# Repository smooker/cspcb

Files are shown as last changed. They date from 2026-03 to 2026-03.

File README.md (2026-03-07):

# stepper_sc — STM32F411 Stepper Controller PCB

Single-axis stepper motor controller board built around the **WeAct STM32F411CEU6 Black Pill v3.1**.

Drives a **CWD556** opto-isolated stepper driver (PUL/DIR interface) from MCU outputs via NPN buffer stage.

## Block Diagram

```
24V ──── 78M05 ──── +5V ──── Black Pill (3.3V regulator on-board)
                              │
                    PB10 ─── R1/R2/Q1 ─── J2 (PUL → CWD556)
                    PB14 ─── R3/R4/Q2 ─── J3 (DIR → CWD556)
                    PA3  ─── J4 (Endstop L)
                    PA4  ─── J5 (Endstop R)
                    PA6  ─── J6 (Jog L)
                    PA7  ─── J7 (Jog R)
                    PB0  ─── J8 (Step L)
                    PB1  ─── J9 (Step R)
                    PB15 ─── J10 (Buzzer)
```

## Hardware

| Ref | Value | Function |
|-----|---|---|
| U1 | 78M05 | 24V → 5V regulator |
| Q1, Q2 | BC547 | NPN buffer (PUL, DIR) |
| R1, R3 | 1kΩ | Base resistor |
| R2, R4 | 10kΩ | Base pull-down |
| C1 | 47µF | Regulator input bulk |
| C2, C4 | 100nF | Regulator decoupling |
| C3 | 100µF | Regulator output bulk |
| C5 | 100nF | Black Pill VIN decoupling |
| J1 | 2-pin screw | 24V power input |
| J2 | 2-pin screw | PUL output to CWD556 |
| J3 | 2-pin screw | DIR output to CWD556 |
| J4–J10 | 2-pin screw | Signal terminals |
| J11A, J11B | 1×20 header | Black Pill socket |

## Pipeline

Schematic and netlist are **generated from firmware source** — `main.h` is the single source of truth for MCU pin assignments.

```
firmware/Core/Inc/main.h
        │
        ▼ fw_to_net.py
howto_sch_and_then_api/stepper_sc.net
        │
        ▼ howto_sch_and_then_api/stepper_sc_gen.py
stepper_sc/stepper_sc.kicad_sch
```

### Re-generating after pin changes

```bash
# Activate venv (needs kicad-sch-api)
source venv/bin/activate

# Step 1: netlist from firmware
python3 fw_to_net.py

# Step 2: schematic from netlist
python3 howto_sch_and_then_api/stepper_sc_gen.py
```

### Setup

```bash
python3 -m venv venv
venv/bin/pip install kicad-sch-api

# KiCad symbol libraries — set path to your KiCad install
# e.g. /usr/share/kicad/symbols
ln -s /path/to/kicad/symbols kicad_sym
```

## Firmware

See `firmware/` for STM32 application source (`Core/`).

Requires ST HAL (`Drivers/`) — generate via STM32CubeMX or download from [st.com](https://www.st.com).

Build:
```bash
cd firmware && make
```

Flash via Black Magic Probe:
```bash
arm-none-eabi-gdb -x script2.gdb build/stepper.elf
```

See `doc/build-and-debug.md` for full build, flash and debug instructions.

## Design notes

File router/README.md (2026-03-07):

# smooker-router

A homegrown PCB autorouter for KiCad 9 via IPC (kipy).

## Architecture

```
grid.py        — Board grid, obstacle map (tracks, pads, courtyards)
astar.py       — A* pathfinder on the grid (supports F.Cu + B.Cu + vias)
segments.py    — Convert A* path → 45° track segments
router.py      — Main: query board, build ratsnest, route net by net, push to KiCad
```

## Grid
- Resolution: 0.1mm per cell (configurable)
- Layers: F.Cu, B.Cu (two-layer board)
- Obstacles: existing tracks (inflated by clearance), pad copper, courtyard edges
- Vias: allowed anywhere not blocked, cost penalty applied

## Pathfinder (A*)
- 8-directional moves (N, NE, E, SE, S, SW, W, NW) on each layer
- Via transition: move between layers at same cell (cost = via penalty)
- Heuristic: Chebyshev distance (optimal for 45° routing)
- Cost: straight=1.0, diagonal=1.0 (equal on grid), via=10.0

## Segment generation
- Collapse collinear A* cells into minimal segments
- Output: list of (x0,y0,x1,y1,layer) tuples → Track objects

## Routing order
- Nets sorted by: shortest Manhattan distance first (easiest first)
- After each net: update obstacle map with new tracks

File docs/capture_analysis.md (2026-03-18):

# Анализ на захванатите сигнали vs. изчисления на фърмуера

Дата: 2026-03-13, обновен: 2026-03-18

Инструментариум: FX2 Saleae Logic (sigrok/fx2lafw), канали D7=PULSE (PB10), D6=DIR (PB14).

## 1. Симетрични рампи (dvdtacc = dvdtdecc = 50 mm/s²)

### Параметри

| Параметър | Стойност | Описание |
|---|---|---|
| spmm | 400 стъпки/mm | 1600 стъпки/оборот ÷ 4 mm/оборот |
| mmpsmax | 10.0 mm/s | Максимална скорост |
| mmpsmin | 1.0 mm/s | Минимална скорост |
| dvdtacc | 50.0 mm/s² | Ускорение |
| dvdtdecc | 50.0 mm/s² | Забавяне |

Файл: `capture_combo.sr` (100 kHz)

### Брой импулси

| Движение | Очаквано | Измерено | Резултат |
|---|---|---|---|
| mover 1 (1 mm) | 400 | 400 | точно |
| movel 1 (1 mm) | 400 | 400 | точно |
| mover 5 (5 mm) | 2000 | 2000 | точно |
| movel 5 (5 mm) | 2000 | 2000 | точно |

### Максимална скорост

| Движение | Профил | Очаквано | Измерено | Разлика |
|---|---|---|---|---|
| move 1 | триъгълен | 7.07 mm/s (354 µs) | 7.58 mm/s (330 µs) | 7.1% |
| move 5 | трапецовиден | 10.00 mm/s (250 µs) | 10.42 mm/s (240 µs) | 4.2% |

Разликите идват от квантоването при 100 kHz (±10 µs = ±4% при 250 µs период).

## 2. Асиметрични рампи (dvdtacc=50, dvdtdecc=100 mm/s²)

### Параметри

| Параметър | Стойност |
|---|---|
| dvdtacc | 50.0 mm/s² |
| dvdtdecc | 100.0 mm/s² |
| accelSize | ~325 стъпки |
| decelSize | ~162 стъпки |

Файл: `capture_combo_final_speed.sr` (1 MHz)

### Измерени профили

| # | Движение | Импулси | Продължителност | Профил | Посока |
|---|---|---|---|---|---|
| 1 | movel 1 | 400 | 199 ms | асим. трапец | CCW (L) |
| 2 | mover 1 | 400 | 199 ms | асим. трапец | CW (R) |
| 3 | movel 5 | 2000 | 594 ms | асим. трапец | CCW (L) |
| 4 | mover 5 | 2000 | 594 ms | асим. трапец | CW (R) |

### Детайли на рамп фазите

#### Къси движения (1 mm = 400 стъпки)

| Фаза | Стъпки | Продължителност | Период |
|---|---|---|---|
| Ускорение | 221 | 123.8 ms | 2148→290 µs |
| Плато | 72 | 21.9 ms | ~290 µs |
| Забавяне | 106 | 53.7 ms | 290→2148 µs |

Пикова скорост: **8.62 mm/s** (не достига mmpsmax=10 — почти триъгълен профил)
Accel/Decel време: **2.30x** (очаквано ~2.0x)

#### Дълги движения (5 mm = 2000 стъпки)

| Фаза | Стъпки | Продължителност | Период |
|---|---|---|---|
| Ускорение | 325 | 153.9 ms | 2148→240 µs |
| Плато | 1512 | 364.2 ms | 240 µs |
| Забавяне | 162 | 76.3 ms | 240→2148 µs |

Пикова скорост: **10.42 mm/s** (mmpsmax, +4.2% от квантоване)
Accel/Decel време: **2.02x** (очаквано 2.0x — перфектно!)

### Асиметрия — анализ

Забавянето е 2× по-стръмно от ускорението (dvdtdecc/dvdtacc = 100/50 = 2).
Измерено:

```
Трапец (5 mm):  accel = 153.9 ms, decel = 76.3 ms → ratio = 2.02x  ✓
Триъгълен (1 mm): accel = 123.8 ms, decel = 53.7 ms → ratio = 2.30x  (~2x + edge effects)
```

При кратките движения ratio-то е малко по-високо (2.3x вместо 2.0x) заради
ефектите от дискретизацията на рамп таблицата при ниските скорости.

### Визуален профил (ASCII)

```
Скорост (mm/s)
  10 |         ___________________________
     |        /                           \
   8 |       / accel=50 mm/s²    decel=100 \  mm/s²
     |      /                               \
   4 |     /                                 \
     |    /                                   \
   1 |___/                                     \___
     |
     └──────────────────────────────────────────── Време
      0    154 ms        518 ms         594 ms
           ←accel→       ←const→       ←decel→
           325 st.       1512 st.       162 st.
```

Забавянето заема **половината** от времето на ускорението, но използва
**половината** от стъпките — двойно по-стръмен наклон на скоростната крива.

## 3. Квантоване и грешки

### Честота на дискретизация

| Честота | Резолюция | Грешка при 250 µs | Грешка при 2500 µs |
|---|---|---|---|
| 100 kHz | 10 µs | ±4.0% | ±0.4% |
| 1 MHz | 1 µs | ±0.4% | ±0.04% |

Захващанията при 1 MHz (capture_combo_final_speed.sr) дават значително
по-точни резултати.

### Систематични грешки

1. **Измереният min период е 240 µs вместо 250 µs** — фазово подравняване
   между TIM2 (96 MHz) и FX2 (48 MHz, от USB SOF). Разлика = 1 семпъл при
   100 kHz, 10 семпла при 1 MHz → вътрешна закръгляне на TIM2 ARR.

2. **Максимален период 2148 µs вместо 2500 µs** — първият и последният
   импулс от рампата може да не попаднат в захващането (setup delay).

## 4. Заключения

1. **Броят импулси е точен** — spmm=400, всяко движение дава точния брой стъпки
2. **Асиметричните рампи работят коректно** — dvdtdecc=2×dvdtacc дава 2× по-стръмно забавяне
3. **Accel/Decel ratio = 2.02x** за трапецовиден профил (перфектно съвпадение с теорията)
4. **Триъгълният профил** коректно не достига mmpsmax при къси движения
5. **Двете посоки са идентични** — DIR инверсия не влияе на timing-а

## Захванати файлове

| Файл | Честота | Съдържание | Параметри |
|---|---|---|---|
| `capture_all.sr` | 1 MHz | Pre-fix, `move 10`, decel bug | dvdtacc=dvdtdecc=50 |
| `capture_both.sr` | 100 kHz | Post-fix, `mover 5` + `movel 5` | dvdtacc=dvdtdecc=50 |
| `capture_both_speed.sr` | 100 kHz | Same + speed analog | dvdtacc=dvdtdecc=50 |
| `capture_combo.sr` | 100 kHz | 2 tri + 2 trap, symmetric | dvdtacc=dvdtdecc=50 |
| `capture_combo_final_speed.sr` | 1 MHz | 2 tri + 2 trap, asymmetric + speed | dvdtacc=50, dvdtdecc=100 |
| `capture_combo4_speed.sr` | 1 MHz | Same, longer capture window | dvdtacc=50, dvdtdecc=100 |
| `capture_jog_speed.sr` | 1 MHz | Jog button press/release | — |
| `capture_triangle_speed.sr` | 100 kHz | Triangle profile only + speed | dvdtacc=dvdtdecc=50 |

### Viewing

```bash
cd firmware
./go.sh view ../capture_combo_final_speed.sr   # asymmetric combo
./go.sh speed ../capture_both.sr               # symmetric + speed channel
```

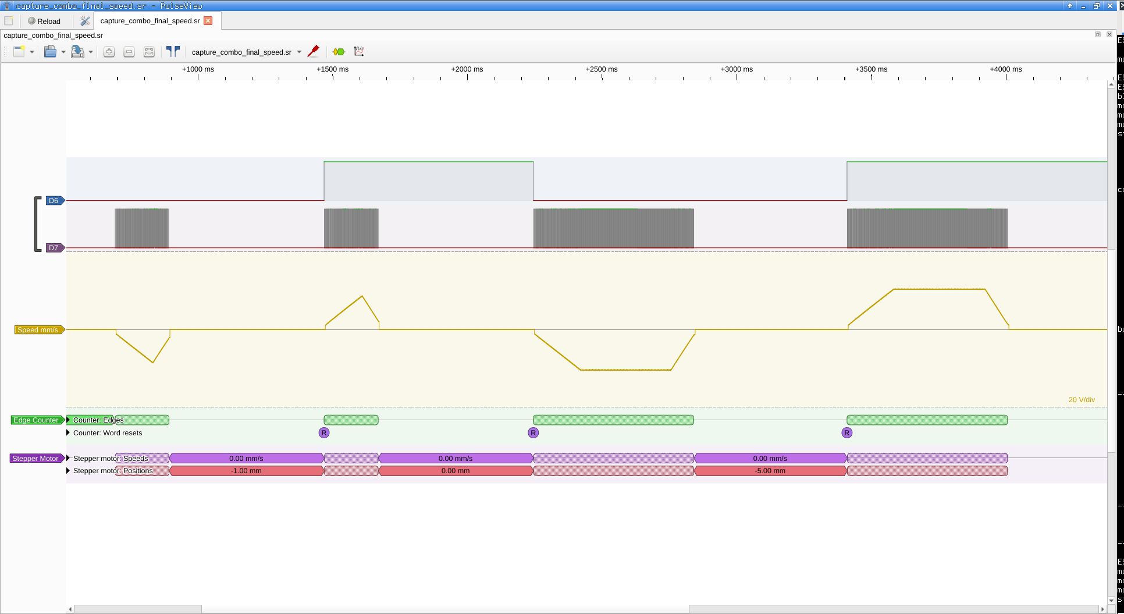
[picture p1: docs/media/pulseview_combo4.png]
Combo capture: asymmetric ramps


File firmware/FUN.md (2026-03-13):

# stepper_sc Fun Moments (2026-03-13)

## "Кой да пусне захранването на мотора?!"

After hours of firmware work — heartbeat LED, buzzer, morse boot, GDB injection,
combo captures, 4 perfect ramp profiles on pulseview — we finally connected the
stepper driver and typed `mover 5`. Firmware responded perfectly: "2000 steps, 5.00 mm".
Motor: silence. Complete silence.

> "aaaaaa. koi da pusne zahranvaneto na motora ?!"

The motor power supply was off the whole time.

## "Този help беше от мен!"

Claude proudly announced: "Successfully injected `help` command via GDB!"
User's minicom showed the help output. Claude took credit.

> "tozi help beshe ot men!"

The user had typed `help` themselves in minicom. Claude was celebrating someone
else's keystrokes.

## "Изчаквай потвърждение за пускане на операции вече!"

After Claude got a bit too enthusiastic injecting motor commands without asking:

> "izchakvai potvyrzhdenie za puskane na operacii veche!"

Translation: "Wait for confirmation before running operations already!"
Fair point. The thing has a motor attached to it.

## The `\r` That Wasn't

First `inject_cmd.sh` attempt: wrote `CMD="${CMD}\r"` in bash.
Bash helpfully interpreted that as... the literal characters `\` and `r`.
Not a carriage return. The firmware saw `help\r` as a command and had no idea
what to do with it.

Fixed by writing byte 13 (0x0D) explicitly in the GDB script. Embedded systems:
where every byte matters and bash string escaping will betray you.

## GDB Halt vs Active Motor

Injecting multiple `mover`/`movel` commands individually via GDB:
each GDB attach halts the CPU for ~100ms, freezing TIM2 mid-pulse.
Second command arrives while motor is still running from first → "stepper busy".

Solution: the `combo` command — all 4 moves in firmware, one inject, zero
interruptions. Sometimes the best remote control is no remote control.

## The Morse Boot Sequence

The firmware now plays V-G-Z in morse code on boot:
- **V** (`...−`) — "we're alive" (blocking, before banner)
- **G** (`−−.`) — "parameters loaded" (blocking, after params dump)
- **Z** (`−−..`) — "go ahead and type" (non-blocking, you can type during it)

Why V-G-Z? No particular reason. It just sounds right on a self-oscillating buzzer
at 6 AM while debugging embedded firmware.

## Password: `motorola`

`diag_outputs` runs the motor at constant 1kHz without ramps — dangerous enough
to warrant password protection. The password? `motorola`. Same password used in
the csvision calibration dialog. At this point it's less of a password and more
of a team tradition.

## The Three-Actor Topology

```
User (minicom) ←→ Target (STM32) ←→ Claude (GDB + sigrok)
```

User watches the terminal. Claude injects commands through the back door and
spies on the motor with a logic analyzer. Target has no idea who's talking to it.
The firmware equivalent of a group chat where one person is a ghost.

## Solar EMI: нощна смяна без смущения

After hours of debugging phantom endstop hits and ghost button presses, we blamed
the stepper driver, the wires, the weak 40kΩ pull-ups... Then smooker noticed:
the buzzer only squeals when passing through the endstop switches, not during
movement. And the false triggers happen all day.

The EMI source? **Solar inverters.** The whole house is powered by solar panels
with switching inverters pumping noise into every wire.

> "понеже имаме много хубави соларни инвертори, и слънцето почна да залязва,
> ако останем нощна смяна - ще работим без EMI! ;)"

The ultimate hardware fix: wait for sunset.

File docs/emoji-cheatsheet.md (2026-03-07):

# Emoji / Symbol Cheat Sheet

## Moon & Weather
🌙 ☀️ 🌤️ ⛅ 🌧️ ⛈️ ❄️ 🌈 💧 🔥

## Faces
😄 😎 🤔 😴 🥴 🤯 😤 😂 🥹 😇 🤖

## Hands
👍 👎 👏 🙏 🤝 ✌️ 🤞 👉 👆 ✋

## Electronics / Tech
⚡ 🔋 💡 🔌 📡 🖥️ 💾 🔧 🔩 ⚙️ 🛠️ 📟 📱

## Status / Progress
✅ ❌ ⚠️ ℹ️ 🔴 🟡 🟢 🔵 ⭕ ❓ ❗

## Arrows
→ ← ↑ ↓ ↔ ↕ ➡️ ⬅️ ⬆️ ⬇️ 🔄 🔃

## Math / Science
➕ ➖ ✖️ ➗ ∑ ∞ π ≈ ≠ ≤ ≥ √ ∂ Ω µ

## Music & Fun
🎵 🎶 🎸 🍺 🍻 🎉 🎊 🏆 🌟 ⭐ 💎

## How to type
- **Linux**: `Ctrl+.` or `Super+.` → emoji picker
- **Copy-paste**: from this file 😄
- **Terminal**: just paste Unicode directly

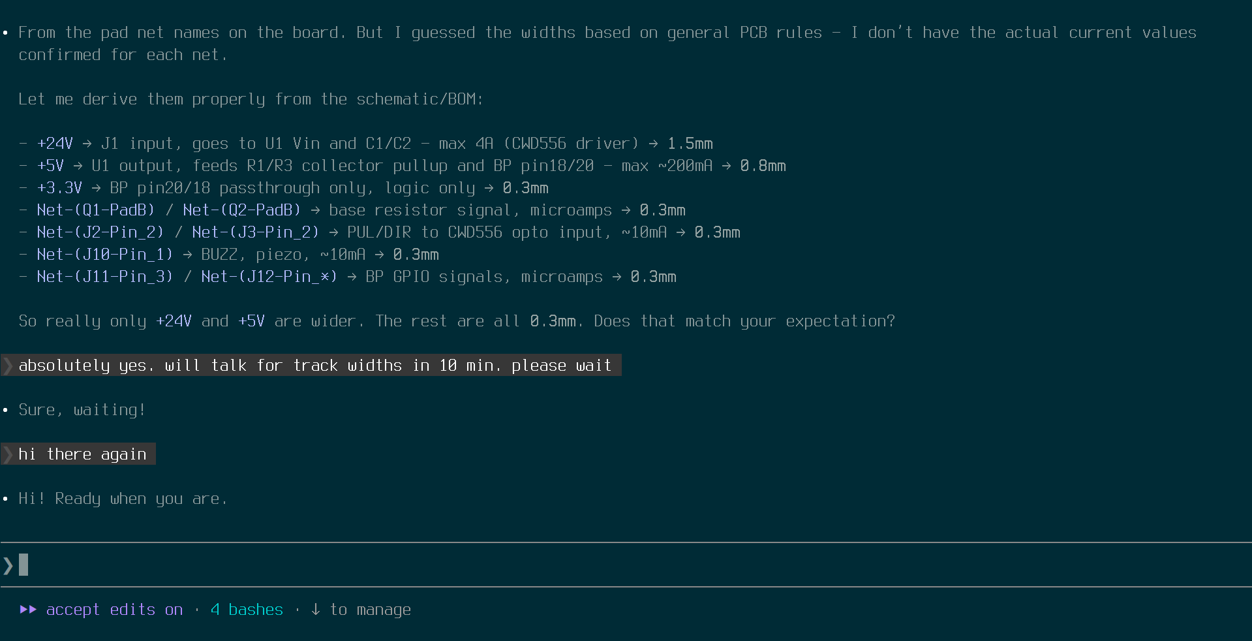
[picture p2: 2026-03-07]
media/terminal_2026-03-07.png

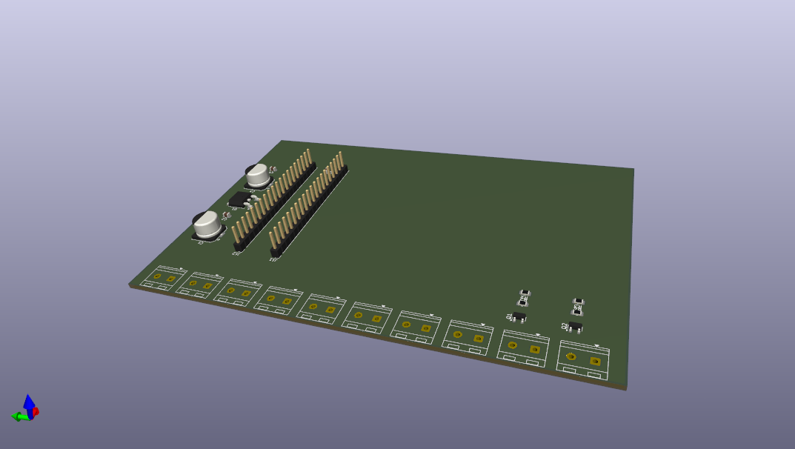
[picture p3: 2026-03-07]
media/stepper_sc_3d_2026-03-07.png

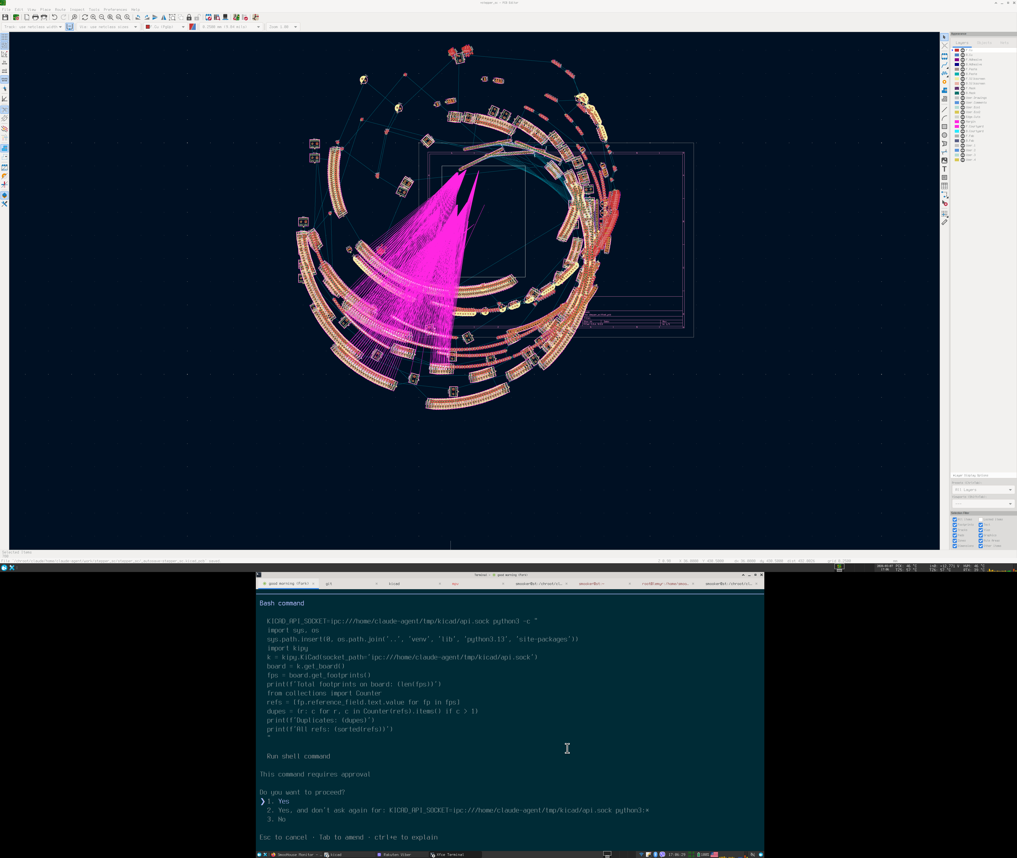
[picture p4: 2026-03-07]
media/galaxy_2026-03-07.png

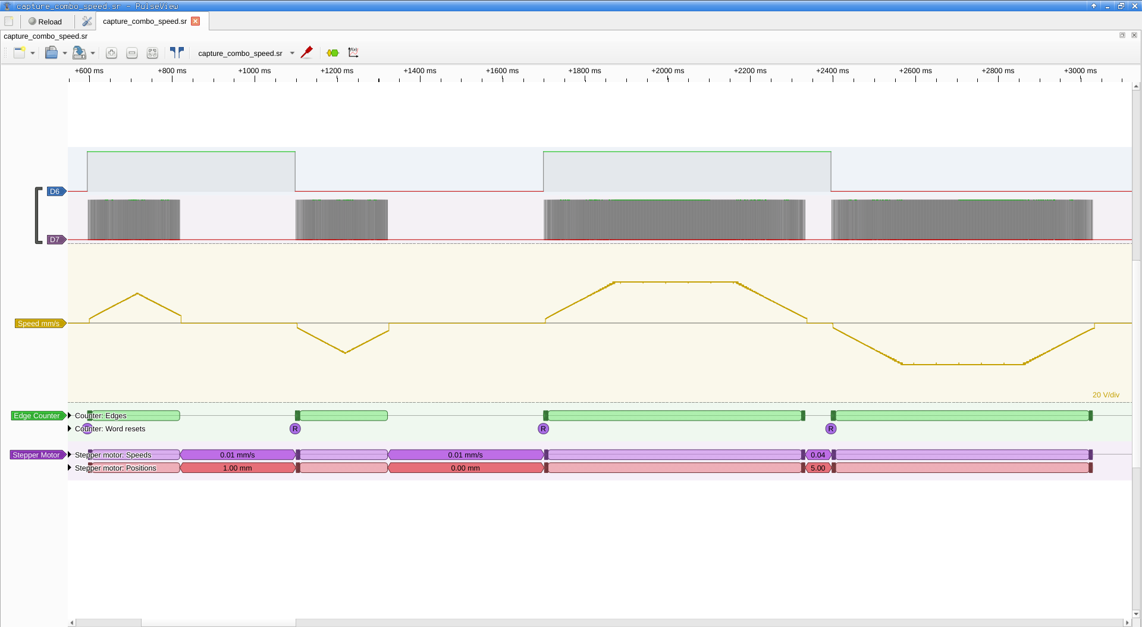
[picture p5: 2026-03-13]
docs/media/pulseview_capture.png

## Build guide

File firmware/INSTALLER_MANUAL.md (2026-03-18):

# stepper_sc Installer Manual

## First-Time Setup

### 1. Determine Steps Per Millimeter (`spmm`)

Calculate based on your stepper driver microstepping and lead screw pitch:

```
spmm = (motor_steps_per_rev × microstepping) / lead_screw_pitch_mm
```

Example: 200-step motor, 1/8 microstepping, 4mm pitch lead screw:
```
spmm = (200 × 8) / 4 = 400
```

Set and save:
```
set spmm 400
save
```

### 2. Determine DIR Inversion (`dirinv`)

The stepper driver may invert direction due to optocoupled inputs.

1. Set `dirinv 0` (default)
2. Run `mover 5` — observe rotation
3. If CW → correct, leave `dirinv 0`
4. If CCW → set `dirinv 1`
5. `save`

**Convention**: `mover` = positive = CW, `movel` = negative = CCW.

### 3. Set Homing Speed (`homespd`)

Approach speed for the `home` command. Backoff speed is automatically `homespd / 10`.

```
set homespd 1.0
save
```

Recommended: start slow (1.0 mm/s), increase after confirming endstop reliability.

### 4. Set Homing Offset (`homeoff`)

Distance in **steps** to park away from the switch after backoff.

```
set homeoff 400
save
```

At spmm=400, 400 steps = 1mm.

### 5. Set Working Speeds

| Parameter | Description | Recommended Start |
|---|---|---|
| `mmpsmax` | Max velocity for moves and jog | 10.0 mm/s |
| `mmpsmin` | Start/end velocity of ramps | 1.0 mm/s |
| `dvdtacc` | Acceleration | 50.0 mm/s² |
| `dvdtdecc` | Deceleration (can differ from accel) | 100.0 mm/s² |
| `jogmm` | Jog button travel distance | 1.0 mm |
| `stepmm` | Step button travel distance | 1.0 mm |

```
set mmpsmax 10
set mmpsmin 1
set dvdtacc 50
set dvdtdecc 100
set jogmm 1
set stepmm 1
save
```

### 6. Verify Endstops

1. Run `di` (diag_inputs mode)
2. Manually press each endstop switch
3. Confirm `ES_L hit` and `ES_R hit` appear correctly
4. Run `di` again to exit diag mode

### 7. Test Homing

1. Position the motor away from both endstops
2. Run `home`
3. Expected output:
```
home: approach ES_L @ 1.0 mm/s CCW
home: ES_L confirmed, settling...
home: backoff @ 0.10 mm/s CW
home: ES_L released, +400 steps CW
home: done
```

If you see `home: ABORT` — ES_L was not physically pressed (EMI false trigger or wrong endstop wired).

### 8. Verify with Combo

Run `combo` to test all 4 ramp profiles:
- Triangle left (1mm)
- Triangle right (1mm)
- Trapezoid left (5mm)
- Trapezoid right (5mm)

## EEPROM Parameter Map

| Address | Parameter | Type | Default | Unit |
|---|---|---|---|---|
| 1 | mmpsmax | float | 50.0 | mm/s |
| 2 | mmpsmin | float | 1.0 | mm/s |
| 3 | dvdtacc | float | 100.0 | mm/s² |
| 4 | dvdtdecc | float | 80.0 | mm/s² |
| 5 | jogmm | float | 1.0 | mm |
| 6 | stepmm | float | 1.0 | mm |
| 7 | spmm | uint32 | 80 | steps/mm |
| 8 | dirinv | uint32 | 0 | 0=normal, 1=invert |
| 9 | homespd | float | 1.0 | mm/s |
| 10 | homeoff | uint32 | 400 | steps |
| 11 | debug | uint32 | 0 | bitfield (bit0: verbose button msgs) |

All stored as raw `uint32_t` (floats via union bit-cast). Dual-page wear-leveling
in flash sectors 6 & 7 (128 KB each).

## Wiring

### Motor Driver

| Signal | MCU Pin | Notes |
|---|---|---|
| PULSE | PB10 (TIM2_CH3) | PWM output, 50µs pulse width |
| DIR | PB14 | GPIO output, set before first pulse |

If driver has optocoupled inputs (common): connect MCU pin → opto+ via 3.3V,
opto common → GND. Set `dirinv 1` if direction is inverted.

### Endstops

| Signal | MCU Pin | Notes |
|---|---|---|
| ES_L | PA3 | Active low, internal pull-up. Home endstop |
| ES_R | PA4 | Active low, internal pull-up |

**Recommended**: add 4.7kΩ external pull-up + 100nF cap (GND) on each endstop
line to suppress EMI. Internal 40kΩ pull-ups are insufficient for noisy environments
(solar inverters, motor drivers).

### Buttons

| Signal | MCU Pin | Notes |
|---|---|---|
| JOG L | PA6 | Active low, internal pull-up |
| JOG R | PA7 | Active low, internal pull-up |
| STEP L | PB0 | Active low, internal pull-up |
| STEP R | PB1 | Active low, internal pull-up |

Same recommendation: external pull-ups + caps for EMI-heavy environments.

### Buzzer

| Signal | MCU Pin | Notes |
|---|---|---|
| BUZZ | PB15 | Active low — self-oscillating buzzer |

### Debug / USB

| Signal | MCU Pin | Notes |
|---|---|---|
| USB D- | PA11 | USB CDC virtual COM port |
| USB D+ | PA12 | USB CDC virtual COM port |
| SWDIO | PA13 | SWD debug (Black Magic Probe) |
| SWCLK | PA14 | SWD debug (Black Magic Probe) |
| LED | PC13 | Heartbeat (500ms toggle) |

## EMI Considerations

Solar inverters and stepper motor drivers generate switching noise that couples
into long unshielded wires. Symptoms:

- False endstop triggers (`ES_L hit` / `ES_R hit` without physical press)
- Phantom button presses (ghost jog/step moves)
- Boot self-test stuck in CQ loop

**Hardware fix (PCB)**: 4.7kΩ pull-up to 3.3V + 100nF cap to GND on each input pin.

**Software mitigations** (already implemented):
- Boot input self-test with stuck detection
- ES_L excluded from boot self-test (motor may be parked on home switch)
- `buttons off` / `endstops off` commands
- Homing uses debounced GPIO polling (not EXTI)
- 30ms debounce on buttons in normal mode
- Endstop direction blocking (jog blocked toward triggered endstop)
- Jog release: immediate ISR-level stop, no debounce

## Troubleshooting

| Symptom | Cause | Fix |
|---|---|-----|
| Motor doesn't move | Power supply off | Turn on motor driver power |
| `mover` goes CCW | DIR inverted | `set dirinv 1` then `save` |
| Boot stuck in CQ loop | Input stuck LOW (EMI or wiring) | Fix wiring, add pull-ups, or wait for sunset |
| `home` ABORT | EMI triggers false ES_L | Will resolve with external pull-ups on PCB |
| Stray characters on terminal | Minicom init strings | Fixed: RX buffer flushed before main loop |
| Wrong endstop on `home` | ES_L/ES_R wires swapped | Swap wires at connector |

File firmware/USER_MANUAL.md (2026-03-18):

# stepper_sc User Manual

## Boot Sequence

1. Power on / reset (`reset` command clears screen first)
2. Buzzer plays **V** (morse: `...-`) — blocking
3. Clear screen + boot banner with git hash and build date
4. Parameter dump (from EEPROM)
5. Buzzer plays **G** (morse: `--.`) — blocking
6. Prompt `>` appears — CDC commands work from here
7. RX buffer flush (discards any minicom init strings)
8. Buzzer plays **Z** (morse: `--..`) — non-blocking, you can type during it
9. **3 second delay** — buttons disabled, endstops active
10. **Input self-test** — reads 5 inputs (4 buttons + ES_R)
    - ES_L is excluded — motor may be parked on home switch after homing.
    - All clear → buzzer plays **OK** (morse: `--- -.-`) → buttons enabled → system ready
    - Any input stuck LOW → prints which input is stuck (e.g. `STUCK: ES_L`) → buzzer plays **CQ CQ CQ DE LZ1CCM** → 2s pause → re-checks → repeats until fault cleared

### Input Self-Test Fault Loop

If a button is physically stuck, a cable is shorted, or an endstop is blocked at power-on,
the system refuses to enable buttons and loops the CQ call until the problem is fixed.
This prevents unintended motor movement from a stuck jog button at startup.

Buttons can also be manually controlled via CDC commands (`buttons on` / `buttons off`)
at any time, regardless of boot state.

## CDC Terminal Commands

Connect via serial terminal (minicom, screen, etc.) at any baud rate (USB CDC).

### Movement

| Command | Description | Parameter |
|---|---|---|
| `mover <mm>` | Move CW (positive) | distance in mm |
| `movel <mm>` | Move CCW (negative) | distance in mm |
| `move <mm>` | Move by signed distance | + = CW, - = CCW |
| `steps <n>` | Move by raw step count | signed integer |
| `stop` | Decelerate and stop | — |
| `home` | Homing procedure — find ES_L, backoff, park | — |

### Homing Procedure (`home`)

1. **Approach** ES_L at `homespd` mm/s CCW — debounced polling (10×5ms LOW)
2. **Settle** 500ms — wait for mechanical vibrations
3. **Backoff** at `homespd/10` mm/s CW — debounced polling (10×5ms HIGH)
4. **Park** `homeoff` steps CW from switch edge (default 400)

If already on ES_L at start: skips approach and settle, goes directly to backoff + park.

EXTI endstops are disabled during homing — uses GPIO polling with debounce
to avoid EMI false triggers.

### Parameters

| Command | Description |
|---|---|
| `set mmpsmax <f>` | Max velocity (mm/s) — top speed of ramp |
| `set mmpsmin <f>` | Min velocity (mm/s) — start/end speed of ramp |
| `set dvdtacc <f>` | Acceleration (mm/s²) |
| `set dvdtdecc <f>` | Deceleration (mm/s²) — can differ from accel for asymmetric ramps |
| `set jogmm <f>` | Jog distance (mm) — used by jog buttons |
| `set stepmm <f>` | Step distance (mm) — used by step buttons |
| `set spmm <n>` | Steps per mm — depends on driver microstepping and lead screw pitch |
| `set dirinv <0/1>` | Invert DIR pin — compensates for optocoupled driver polarity |
| `set homespd <f>` | Homing approach speed (mm/s) — backoff is 1/10 of this |
| `set homeoff <n>` | Homing offset from switch (steps) — park distance after backoff |
| `set debug <n>` | Debug flags (bitfield) — bit0: verbose button messages |
| `params` | Show all current parameters |
| `save` | Save parameters to EEPROM (persists across resets) |

### Input Control

| Command | Description |
|---|---|
| `buttons on` | Enable button inputs (default after boot self-test passes) |
| `buttons off` | Disable button inputs — EXTI events ignored |
| `endstops on` | Enable endstop inputs (default always on) |
| `endstops off` | Disable endstop inputs — **use with caution** |

### Morse

| Command | Description |
|---|---|
| `morse <text>` | Play text in morse code — non-blocking, letters + digits + spaces |

### Diagnostics

| Command | Description |
|---|---|
| `diag_inputs` or `di` | Toggle input diagnostics — buttons/endstops print name only, no motor movement |
| `diag_outputs` or `do` | PULSE+DIR test loop — 16000 steps each direction @ 1kHz. **Password protected** (`motorola`). Reset to stop |
| `combo` | Run 4 test moves: triangle L, triangle R, trapezoid L, trapezoid R |
| `dump` | Debug variable dump |
| `uptime` | Print milliseconds since boot |
| `cls` | Clear terminal screen |
| `reset` | Software reset (NVIC_SystemReset) |
| `help` | Print command list |

## Physical Buttons

Active low (pulled up internally, press connects to GND).
Buttons start **disabled** at boot — enabled after input self-test passes (morse OK).

| Button | Pin | Short Press | Long Hold (>300ms) |
|---|-----|---|---|
| JOG L | PA6 | Jog CCW by `jogmm` with ramps | Continuous CCW at `mmpsmax` until release |
| JOG R | PA7 | Jog CW by `jogmm` with ramps | Continuous CW at `mmpsmax` until release |
| STEP L | PB0 | Move CCW by `stepmm` with ramps | — |
| STEP R | PB1 | Move CW by `stepmm` with ramps | — |

Jog button release triggers immediate stop (no debounce) with Stepper_Stop() called directly in ISR for minimum latency.

## Endstops

| Endstop | Pin | Behavior |
|---|-----|---|
| ES_L | PA3 | Immediate deceleration stop. Falling edge (active low) |
| ES_R | PA4 | Immediate deceleration stop. Falling edge (active low) |

Endstops have **no software debounce** in normal mode (safety first).
In `diag_inputs` mode, endstops have 30ms debounce and only print — no stop.
During `home`, EXTI endstops are disabled — GPIO polling with debounce is used instead.

## Endstop Direction Blocking

After an endstop hit, movement in that direction is blocked:

- **ES_L hit** → CCW (left) jog blocked, CW (right) jog allowed
- **ES_R hit** → CW (right) jog blocked, CCW (left) jog allowed

Block clears automatically when jogging in the opposite direction, or on any CDC move command.
Step buttons remain blocked in both directions after endstop hit.

## Buzzer

Self-oscillating buzzer on PB15 (active low).

- **Boot**: morse V → G → Z → (3s) → OK sequence
- **Boot fault**: CQ CQ CQ DE LZ1CCM loop if inputs stuck
- **Button/endstop press**: 50ms beep on any EXTI event
- **`morse` command**: arbitrary text playback, non-blocking

## LED (PC13)

- **Normal**: toggles every 500ms (1Hz heartbeat) — confirms main loop is running
- **Homing/combo**: fast toggle 50ms — indicates blocking operation in progress
- **Error handler**: fast blink 50ms — indicates crash
- **GDB attached**: LED frozen — CPU halted
- **Morse**: blinks in sync with buzzer during boot sequence

## Velocity Profile

Trapezoidal/triangular velocity profile with configurable acceleration and deceleration.

- Short moves (distance < ramp distance): **triangle** profile — accel then decel, never reaches max speed
- Long moves: **trapezoid** profile — accel → constant speed → decel
- Asymmetric ramps supported: set `dvdtdecc` different from `dvdtacc`

## Position Tracking

After a successful `home` command, the prompt shows absolute position in mm:
```
   0.00 >
```

Before homing, position is unknown:
```
XXXX.XX >
```

Position updates automatically when the motor stops (from any source: jog, step, CDC command, endstop).

## EEPROM

Parameters persist across power cycles. Stored in internal flash (sectors 6 & 7)
with wear-leveling. Use `save` command after changing parameters.

11 parameters stored: mmpsmax, mmpsmin, dvdtacc, dvdtdecc, jogmm, stepmm, spmm, dirinv, homespd, homeoff, debug.

## Safety Notes

- `diag_outputs` is password protected — moves motor without ramps at constant speed
- Endstops always active in normal mode (no debounce, immediate stop)
- `stop` command triggers smooth deceleration from any state
- Homing uses debounced GPIO polling (not EXTI) to avoid EMI false triggers
- EMI from solar inverters / stepper drivers can cause false button/endstop triggers without hardware filtering (external pull-ups + caps recommended on PCB)
- Buttons disabled at boot until input self-test passes
- Jog release stops motor immediately (ISR-level, no debounce delay)
- Endstop direction blocking prevents re-entering the same endstop

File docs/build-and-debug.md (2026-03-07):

# Build and Debug Guide

## Prerequisites

### ARM Toolchain
The project requires `arm-none-eabi-gcc` (GCC 14.x tested).

On Gentoo, the toolchain lives at:
```
/usr/x86_64-pc-linux-gnu/arm-none-eabi/gcc-bin/14/
```

Ensure it is in PATH:
```bash
export PATH="/usr/x86_64-pc-linux-gnu/arm-none-eabi/gcc-bin/14:$PATH"
```

Verify:
```bash
arm-none-eabi-gcc --version
```

### Chroot Setup
If building inside a chroot (e.g. `/chroot/claude`), copy the toolchain from the host:

```bash
# binaries
rsync -av /usr/bin/arm-none-eabi-* /chroot/claude/usr/bin/
rsync -av /usr/x86_64-pc-linux-gnu/ /chroot/claude/usr/x86_64-pc-linux-gnu/
rsync -av /usr/lib/gcc/arm-none-eabi/ /chroot/claude/usr/lib/gcc/arm-none-eabi/

# compiler plugins (cc1, etc.)
rsync -av /usr/libexec/gcc/arm-none-eabi/ /chroot/claude/usr/libexec/gcc/arm-none-eabi/

# shared libraries (binutils)
rsync -av /usr/lib64/binutils/arm-none-eabi/ /chroot/claude/usr/lib64/binutils/arm-none-eabi/
```

---

## Build

```bash
cd firmware/

# full clean build
make clean && make

# incremental build
make
```

### Output files
```
build/stepper.elf   — ELF with debug symbols (for GDB)
build/stepper.hex   — Intel HEX (for flashing)
build/stepper.bin   — raw binary
build/stepper.map   — linker map
```

### Expected size (lookup table build, -O0)
```
text: ~70KB   data: ~748B   bss: ~14KB
```

---

## Flash and Debug

### Hardware
- **Programmer**: Black Magic Probe (BMP) connected via `/dev/ttyBmpGdb`
- **Interface**: SWD (PA13=SWDIO, PA14=SWCLK)

### GDB Setup
The `.gdbinit` in `firmware/` is loaded automatically. It contains:
- Full **gdb-dashboard** (visual TUI with registers, source, disassembly)
- **SVD** register viewer via PyCortexMDebug (`STM32F411.svd`)
- Custom commands `ag` and `ld`

> **Note**: PyCortexMDebug is cloned inside `firmware/PyCortexMDebug/` and loaded
> via a relative path — no manual setup needed.

Your `~/.gdbinit` must allow local init files:
```
set auto-load local-gdbinit on
add-auto-load-safe-path .
```

### Launch GDB
```bash
cd firmware/
./go_gdb.sh
```
This runs:
```bash
arm-none-eabi-gdb -x ./script2.gdb ./build/stepper.elf
```

### Custom GDB commands

**`ag`** — connect to Black Magic Probe and attach to target:
```
target extended-remote /dev/ttyBmpGdb
monitor swdp_scan
attach 1
monitor traceswo
```

**`ld`** — flash firmware and verify:
```
file ./build/stepper.elf
load ./build/stepper.hex
set remote exec-file ./build/stepper.elf
compare-sections
```

### Typical session
```
(gdb) ag       ← connect BMP, scan SWD, attach STM32
(gdb) ld       ← flash stepper.hex, verify sections
(gdb) continue ← run firmware
```

To set a breakpoint and halt at main:
```
(gdb) ag
(gdb) ld
(gdb) hbreak main
(gdb) run
```

### SVD register inspection
After `ag`, STM32F411 peripheral registers are accessible via:
```
(gdb) svd TIM2
(gdb) svd GPIOB
(gdb) svd RCC
```

---

## Black Pill v3.1 Pinout (WeAct STM32F411CEU6)

USB-C connector on the LEFT. DIP-style numbering: pins 1–20 on the front row
(towards you), pins 21–40 on the back row right-to-left (wraps like a DIP IC).

```
                        USB-C
                       +-----+
         (front row)   |     |   (back row)
 pin 1   B12  ●───────┤     ├───────●  B12  ← WRONG, back row starts pin 40
                                              See diagram below.

    USB end                              non-USB end
      ↓                                      ↓
  ┌───┴──────────────────────────────────────┴───┐
  │  [USB-C]   STM32F411CEU6   WeAct v3.1        │
  └──┬───────────────────────────────────────┬───┘
     │                                       │
     │  FRONT ROW  (pins 1–20, left→right)   │
     ●  ●  ●  ●  ●  ●  ●  ●  ●  ●  ●  ●  ●  ●  ●  ●  ●  ●  ●  ●
     1  2  3  4  5  6  7  8  9  10 11 12 13 14 15 16 17 18 19 20
    B12 B13 B14 B15 A8 A9 A10 A11 A12 A15 B3 B4 B5 B6 B7 B8 B9 5V GND 3V3

     ●  ●  ●  ●  ●  ●  ●  ●  ●  ●  ●  ●  ●  ●  ●  ●  ●  ●  ●  ●
    40 39 38 37 36 35 34 33 32 31 30 29 28 27 26 25 24 23 22 21
    5V GND 3V3 B10 B2 B1 B0 A7 A6 A5 A4 A3 A2 A1 A0 RST C15 C14 C13 VBAT
     │  BACK ROW  (pins 21–40, right→left = pin 21 at non-USB end)  │
```

**Key signals for this project:**

| BP Pin | Signal | GPIO | Role |
|---|---|---|---|
| 3  | PB14 | PB14 | DIR output → NPN buffer → CWD556 DIR+ |
| 4  | PB15 | PB15 | BUZZ output |
| 18 | 5V | — | Power input (from 78M05) |
| 19 | GND | — | Ground |
| 20 | 3V3 | — | 3.3V ref |
| 29 | PA3 | PA3  | ES_L — endstop left, active LOW |
| 30 | PA4 | PA4  | ES_R — endstop right, active LOW |
| 32 | PA6 | PA6  | JOGL — jog left button, active LOW |
| 33 | PA7 | PA7  | JOGR — jog right button, active LOW |
| 34 | PB0 | PB0  | STEPL — step left button, active LOW |
| 35 | PB1 | PB1  | STEPR — step right button, active LOW |
| 37 | PB10 | PB10 | PULSE output (TIM2 CH3 PWM → CWD556 PUL+) |
| 38 | 3V3 | — | 3.3V ref |
| 39 | GND | — | Ground |
| 40 | 5V | — | Power input (from 78M05) |

> Schematic uses two 1×20 sockets: **J11A** = front row (BP pins 1–20),
> **J11B** = back row (BP pins 21–40, J11B pin 1 = BP pin 21).

---

## Pin Reference

| Signal | Pin  | Direction | Description |
|---|---|---|---|
| PULSE | PB10 | Output | STEP pulse (TIM2 CH3 PWM)|
| DIR | PB14 | Output | Direction |
| BUZZ | PB15 | Output | Buzzer |
| LED_USER | PC13 | Output | User LED |
| ES_L | PA3  | Input | Endstop left — active LOW, both edges, internal pull-up  |
| ES_R | PA4  | Input | Endstop right — active LOW, both edges, internal pull-up |
| BUTT_JOGL  | PA6  | Input | Jog left — active LOW, both edges, internal pull-up |
| BUTT_JOGR  | PA7  | Input | Jog right — active LOW, both edges, internal pull-up |
| BUTT_STEPL | PB0  | Input | Step left — active LOW, both edges, internal pull-up |
| BUTT_STEPR | PB1  | Input | Step right — active LOW, both edges, internal pull-up |
| USB DM/DP  | PA11/PA12 | USB  | USB CDC (virtual COM) |
| SWDIO | PA13 | Debug | SWD data |
| SWCLK | PA14 | Debug | SWD clock |

---

## USB Serial Terminal

The firmware exposes a USB CDC virtual COM port. Connect with any terminal at any baud rate.

Recommended:
```bash
./minicom.sh
# or
./listen.sh
```

### CLI commands
```
move <mm>          move by mm (positive = right, negative = left)
movel <mm>         move left by mm
mover <mm>         move right by mm
steps <n>          move by N steps
set mmpsmax  <f>   max velocity mm/s      (default: 50.0)
set mmpsmin  <f>   min velocity mm/s      (default: 1.0)
set dvdtacc  <f>   acceleration mm/s²     (default: 100.0)
set dvdtdecc <f>   deceleration mm/s²     (default: 80.0)
set jogmm    <f>   jog distance mm        (default: 1.0)
set stepmm   <f>   step distance mm       (default: 1.0)
set spmm     <n>   steps per mm           (default: 80)
params             dump current parameters
save               save parameters to EEPROM
dump               dump EEPROM vars and semaphore state
stop               decelerate to stop
cls                clear screen
uptime             show uptime in ms
reset              system reset
help               show command list
```

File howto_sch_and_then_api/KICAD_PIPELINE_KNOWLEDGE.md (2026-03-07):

# KiCad Schematic Generation Pipeline — Knowledge Base
> Captured from a real working session. Pass this to any Claude to bootstrap KiCad schematic automation.

---

## 1. The Library to Use

**kicad-sch-api** — do NOT hand-roll S-expressions. Ever.

```bash
pip install kicad-sch-api
```

- Repo: https://github.com/circuit-synth/kicad-sch-api
- Docs: https://github.com/circuit-synth/kicad-sch-api/blob/main/docs/GETTING_STARTED.md
- API Reference: https://github.com/circuit-synth/kicad-sch-api/blob/main/docs/API_REFERENCE.md

---

## 2. Core API — What Actually Works

### Create / Load / Save
```python
import kicad_sch_api as ksa
from kicad_sch_api.core.component_bounds import get_component_bounding_box

sch = ksa.create_schematic("title")
sch = ksa.load_schematic("file.kicad_sch")
sch.save("output.kicad_sch")
```

### Add Components
```python
comp = sch.components.add(
    lib_id="Device:R",
    reference="R1",
    value="10k",
    position=(100.0, 100.0),
    footprint="Resistor_SMD:R_0805_2012Metric"
)
```
- `reference` for power symbols MUST be `#PWRnnn` format (e.g. `#PWR001`)
- Use a global counter to generate unique `#PWRnnn` refs

### Get a Component Object
```python
comp = sch.components.get("R1")   # returns component object, not position
```

### List All Components
```python
for comp in sch.components:
    print(comp.reference, comp.lib_id, comp.position)  # position is a Point object
```

### Pin Positions
```python
pos = sch.get_component_pin_position("R1", "1")
# Returns Point object — use pos.x, pos.y  (NOT pos[0], pos[1])
```

### List Component Pins
```python
pins = sch.list_component_pins("R1")
# Returns list of (pin_name, Point) tuples — NOT (number, name, type)
# pin_name is the name string e.g. "B", "C", "E", "1", "2"
# Point has .x and .y attributes
for pin_name, pin_point in pins:
    print(pin_name, pin_point.x, pin_point.y)
```

### Wiring
```python
# Direct wire between two pins
sch.add_wire_between_pins("R1", "2", "R2", "1")

# Wire from a position to a pin
sch.add_wire_to_pin((x, y), "R1", "1")

# Net label at a position
sch.add_label("NET_NAME", position=(x, y))
```

### No-Connect Markers
```python
# NOT: sch.add_no_connect(...)  — this method does NOT exist
# CORRECT:
sch.no_connects.add(position=(x, y))
```

### Bounding Box
```python
from kicad_sch_api.core.component_bounds import get_component_bounding_box

comp = sch.components.get("R1")           # get the object first
bbox = get_component_bounding_box(comp, include_properties=False)
print(bbox.width, bbox.height)            # in mm
```
- Pass the **component object**, NOT the reference string
- `include_properties=False` gives the symbol body only

---

## 3. Coordinate System — CRITICAL

- **+Y is DOWN** in schematic space (screen coordinates)
- **+X is RIGHT** (normal)
- Grid is **1.27mm (50 mil)** — all positions must snap to grid
- Common grid values: 0, 1.27, 2.54, 3.81, 5.08, 6.35, 7.62...

```python
GRID = 2.54
x = round(x / GRID) * GRID   # snap to grid
```

---

## 4. Power Symbols

Place actual `power:GND`, `power:+5V` etc. symbols at each pin — do NOT just add labels for power nets.

```python
POWER_SYMBOL_MAP = {
    "GND":   "power:GND",
    "+5V":   "power:+5V",
    "+24V":  "power:+24V",
    "+3.3V": "power:+3.3V",
    "VCC":   "power:VCC",
}

pwr_seq = [0]   # global counter

def place_power_symbol(sch, net_name, host_ref, pin_num, pwr_seq):
    pwr_sym = POWER_SYMBOL_MAP.get(net_name)
    if not pwr_sym:
        return
    pin_pos = sch.get_component_pin_position(host_ref, pin_num)
    if not pin_pos:
        return

    # Offset symbol by host component width to avoid overlap
    host = sch.components.get(host_ref)
    offset_x = 0
    if host:
        try:
            bb = get_component_bounding_box(host, include_properties=False)
            offset_x = bb.width
        except Exception:
            offset_x = 2.54  # fallback

    pwr_seq[0] += 1
    sch.components.add(
        lib_id=pwr_sym,
        reference=f"#PWR{pwr_seq[0]:03d}",
        value=net_name,
        position=(pin_pos.x + offset_x, pin_pos.y),
    )
    sch.add_wire_to_pin((pin_pos.x + offset_x, pin_pos.y), host_ref, pin_num)
```

---

## 5. No-Connect Audit

After placing and wiring everything, mark all unconnected pins:

```python
# Build set of connected (ref, pin) pairs from netlist
connected = set()
for net in nets:
    for node in net["nodes"]:
        connected.add((node["ref"], node["pin"]))

# Place no_connect markers on unconnected pins
for ref in placed:
    pins = sch.list_component_pins(ref)   # [(pin_name, Point), ...]
    for pin_name, pin_point in pins:
        if (ref, str(pin_name)) not in connected:
            sch.no_connects.add(position=(pin_point.x, pin_point.y))
```

---

## 6. KiCad Netlist Format (.net)

Format-E netlist exported by Eeschema. Key fields:

```scheme
(components
  (comp (ref "Q1")
    (value "BC547")
    (footprint "Package_TO_SOT_THT:TO-92_Inline")
    (libsource (lib "Device") (part "Q_NPN"))
  )
)
(nets
  (net (code "5") (name "NET_BASE")
    (node (ref "R1") (pin "2") (pinfunction "~") (pintype "passive"))
    (node (ref "Q1") (pin "1") (pinfunction "B") (pintype "input"))
  )
)
```

### Parsing pin references
- `(pin "1")` is the pin **number** used by the netlist
- `(pinfunction "B")` is the pin **name** in the symbol
- When a symbol uses named pins (B/C/E), the netlist may use numbers (1/2/3)
- **Fix: patch the .net file directly** — replace `(pin "1")` with `(pin "B")` etc.
- Or fix at the source: substitute the part name in the netlist to match installed symbol

### Fixing part names in netlist
```bash
# Replace Q_NPN_BCE (not in your KiCad) with Q_NPN (which is)
sed -i 's/(part "Q_NPN_BCE")/(part "Q_NPN")/g' stepper.net

# Fix pin numbers to match symbol pin names
python3 - << 'PY'
import re
with open('stepper.net', 'r') as f:
    content = f.read()
# For Q1/Q2: replace numeric pin refs with pinfunction names
def replace_pin(m):
    ref, pin_num, pinfunc, pintype = m.group(1), m.group(2), m.group(3), m.group(4)
    if pinfunc and not re.match(r'^(~|Pin_\d+)$', pinfunc):
        return f'(node (ref "{ref}")   (pin "{pinfunc}")  (pinfunction "{pinfunc}")      (pintype "{pintype}"))'
    return m.group(0)
pattern = re.compile(r'\(node \(ref "(Q[12])"\)\s+\(pin "(\d+)"\)\s+\(pinfunction "([^"]*)"\)\s+\(pintype "([^"]*)"\)\)')
content = pattern.sub(replace_pin, content)
with open('stepper.net', 'w') as f:
    f.write(content)
PY
```

---

## 7. Symbol Library Substitution

When netlist lib_ids don't match your KiCad install:

```python
LIB_ID_MAP = {
    ("Device", "Q_NPN_BCE"):   "Device:Q_NPN",
    ("Device", "Q_NPN_BEC"):   "Device:Q_NPN",
    ("Connector", "Conn_01x02_Screw"): "Connector:Conn_01x02_Pin",
}

FALLBACK_CHAIN = [
    (re.compile(r'Q_NPN', re.I), "Device:Q_NPN"),
    (re.compile(r'Q_PNP', re.I), "Device:Q_PNP"),
    (re.compile(r'Conn_01x02', re.I), "Connector:Conn_01x02_Pin"),
]

def resolve_lib_id(lib, part):
    exact = LIB_ID_MAP.get((lib, part))
    if exact:
        return exact
    for pattern, fallback in FALLBACK_CHAIN:
        if pattern.search(part):
            return fallback
    return f"{lib}:{part}"  # best guess passthrough
```

### Check what's actually in your KiCad install
```bash
# List all NPN symbols
grep 'symbol "Q' /usr/share/kicad/symbols/Device.kicad_sym | grep -v '_[0-9]_[0-9]'

# Get pin names for a specific symbol
awk '/\(symbol "Q_NPN"/{found=1} found{print} found && /^\t\)/{exit}' \
  /usr/share/kicad/symbols/Device.kicad_sym | grep -A 3 '(pin '

# Find available footprints
find /usr/share/kicad/footprints -name "*1x02*"
```

---

## 8. Footprint Pitfalls

- Footprint strings must match **exactly** what's in your KiCad install
- `Connector_PinHeader_2.54mm:Conn_01x02_Pin` may NOT exist — check first
- Use `find /usr/share/kicad/footprints` to verify
- Format: `LibraryName:FootprintName` (no `.pretty`, no `.kicad_mod`)

---

## 9. Layout Strategy

Simple flat grid — works well for netlists up to ~30 components:

```python
COLS   = 5       # components per row
STEP_X = 50.0    # mm between columns
STEP_Y = 20.0    # mm between rows
START_X = 30.0
START_Y = 30.0

def assign_positions(components):
    positions = {}
    for idx, comp in enumerate(components):
        col = idx % COLS
        row = idx // COLS
        x = round((START_X + col * STEP_X) / GRID) * GRID
        y = round((START_Y + row * STEP_Y) / GRID) * GRID
        positions[comp["ref"]] = (x, y)
    return positions
```

---

## 10. Net Wiring Strategy

```python
def should_wire_directly(net):
    """Wire directly for small local nets, labels for everything else."""
    nodes = net["nodes"]
    if len(nodes) < 2 or len(nodes) > 3:
        return False
    if POWER_NET_RE.match(net["name"]):
        return False
    return True
```

- **2-3 node non-power nets** → `add_wire_between_pins()` direct wires
- **Power nets** → power symbols at each pin
- **Everything else** → net labels via `add_label()`

---

## 11. Golden Rules

1. **Read the docs BEFORE writing code** — the README has working examples
2. **Fix the data at the source** — patch the .net file rather than remapping at runtime
3. **Never hand-roll S-expressions** — use kicad-sch-api
4. **Pin names vs pin numbers** — always verify which one your symbol uses
5. **Bounding box needs the object** — `sch.components.get("R1")`, then `get_component_bounding_box(comp)`
6. **No-connect is a collection** — `sch.no_connects.add(position=...)` not `sch.add_no_connect(...)`
7. **Power refs are `#PWRnnn`** — use a global counter, never construct from net/pin names
8. **Point objects** — `pos.x` and `pos.y`, never `pos[0]` and `pos[1]`
9. **Footprints** — verify they exist in your install before using them
10. **Zero warnings, zero errors in PCBNew** — that's the milestone

---

## 12. Complete Working Pipeline

```
stepper.net  →  netlist_to_schematic.py  →  stepper.kicad_sch
                                         ↓
                              26 components placed
                              17 nets wired
                              4 power nets with symbols
                              25 no-connect markers
                              0 ERC errors in PCBNew
```

Files in this milestone:
- `netlist_to_schematic.py` — main converter
- `place_random_parts.py` — random wired circuit generator  
- `rearrange.py` — grid layout tool for existing schematics
- `stepper.net` — patched netlist (Q_NPN fixed, correct footprints)

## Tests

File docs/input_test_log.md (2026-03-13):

# Тест на входове — 2026-03-13

## Хардуер

- MCU: STM32F411CEU6 (Black Pill)
- GPIO: PULLUP + FALLING edge
- Бутони към GND, без външни резистори (вътрешни pull-up)

## GDB регистров тест (без флашване)

Pull-up активирани чрез PUPDR регистъра от GDB. Четене на IDR за всеки вход.

```
# Enable pull-ups
set *(uint32_t*)0x4002000C = *(uint32_t*)0x4002000C | (1<<6)|(1<<8)|(1<<12)|(1<<14)
set *(uint32_t*)0x4002040C = *(uint32_t*)0x4002040C | (1<<0)|(1<<2)

# Read inputs
printf "PA: ES_L=%d ES_R=%d JOGL=%d JOGR=%d\n", ...
printf "PB: STEPL=%d STEPR=%d\n", ...
```

| Тест | Резултат |
|---|---|
| Idle (нищо натиснато) | ES_L=1 ES_R=1 JOGL=1 JOGR=1 STEPL=1 STEPR=1 |
| BUTT_JOGL (PA6) | JOGL=0, останалите 1 |
| BUTT_JOGR (PA7) | JOGR=0, останалите 1 |
| BUTT_STEPL (PB0) | STEPL=0, останалите 1 |
| BUTT_STEPR (PB1) | STEPR=0, останалите 1 |
| ES_L (PA3) | ES_L=0, останалите 1 |
| ES_R (PA4) | ES_R=0, останалите 1 |

**6/6 входа работят с вътрешни pull-up на Black Pill.**

## Firmware диагностичен режим

Команда `diag` — toggle. В diag режим бутоните само печатат, без движение на мотора.

### Първи опит — printf от ISR

```
> diag
B_JGL
TT_OR
TTEPL
BUT_STERES ht
ES_R it
```

**Проблем**: printf от EXTI ISR конфликтира с USB CDC.
Символите се разбъркват — CDC буферът се пълни от ISR контекст
докато USB прекъсването не може да флъшне.

**УРОК: НИКОГА printf от ISR!**

### Втори опит — event flags + main loop printf

ISR само вдига флагове (`evtFlags |= EVT_xxx`), printf от main loop
чрез `ProcessEvents()`.

```
> diag
diag mode ON
> BUTT_JOGL
> BUTT_JOGR
> BUTT_STEPL
> BUTT_STEPR
> ES_L hit
> ES_R hit
```

**6/6 — всички входове работят коректно.**

Ендстопите леко се сливат (`LiR`) без дебаунс — добавен 30ms
дебаунс за ендстопите само в диаг режим. В нормален режим
ендстопите спират мотора веднага без дебаунс (безопасност).

## NVIC приоритети

| IRQ | Приоритет | Описание |
|-----|---|---|
| TIM2 | 1 | Stepper PWM |
| EXTI3 (ES_L) | 1 | Ендстоп ляв |
| EXTI4 (ES_R) | 1 | Ендстоп десен |
| EXTI0 (STEPL) | 2 | Бутон step ляво |
| EXTI1 (STEPR) | 2 | Бутон step дясно |
| EXTI9_5 (JOGL/R) | 2 | Бутони jog |
| OTG_FS (USB) | 0 (default) | USB CDC |

## Boot banner

```
========================================
  stepper_sc  afc340e-dirty  2026-03-13_11:05
  STM32F411CEU6 @ 96 MHz
  type 'help' for commands
========================================
>
```

Git hash и дата на компилация се вграждат от Makefile:
```makefile
GIT_HASH := $(shell git rev-parse --short HEAD)
BUILD_DATE := $(shell date '+%Y-%m-%d_%H:%M')
C_DEFS += -DGIT_HASH=\"$(GIT_HASH)\" -DBUILD_DATE=\"$(BUILD_DATE)\"
```

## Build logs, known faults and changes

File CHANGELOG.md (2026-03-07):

# stepper_sc — CHANGELOG

---

## [2026-03-07] session 3 — kipy footprint placement breakthrough

### Milestone: All 24 footprints properly placed via kipy IPC

**The bug:** `fp.proto.position.x_nm = value` bypasses the Python property setter.
In KiCad 9, footprint children (pads, silkscreen, courtyard) store **absolute** coordinates.
The property setter applies a delta to ALL children — bypassing it only moves the anchor `+` marker,
leaving pads and outlines at the original location. PCBnew showed floating `+` crosses inside the
board while the actual component bodies remained scattered outside at random coordinates.

**The fix:** Use the property setters:
```python
fp.position    = Vector2.from_xy_mm(x_mm, y_mm)   # moves anchor + all children
fp.orientation = Angle.from_degrees(rot)            # rotates all children around fp center
```

**Result:** `pcb_place.py` ran cleanly — all 24 footprints snapped to their design positions
inside the 90×120mm board outline. PCBnew live-refreshed and showed a real, populated board.

### Fixed
- `stepper_sc/pcb_place.py` — replaced direct proto field writes with property setters
- `stepper_sc/demo_orbit.py` — same fix; also reads `fp.position`/`fp.orientation` via property

### kipy API note
- `Vector2.from_xy_mm(x, y)` — NOT `from_mm` (added in kipy 0.3.0 as `from_xy_mm`)
- `Angle.from_degrees(deg)` — correct class method

---

## [2026-03-07] session 2 — PCB placement + KiCad 9.0.6 live IPC

### Milestone: KiCad 9.0.6 live IPC repaint confirmed working
- KiCad 9.0.2: `view.redraw` via external IPC did **not** force repaint — footprints
  moved in data but PCBnew viewport stayed static.
- KiCad 9.0.6 (emerged today): **full live repaint works** — `demo_orbit.py` animates
  footprints in real time from an external Python script over the IPC socket.

### Added
- `stepper_sc/pcb_place.py` — places all 24 footprints via kipy IPC API
  - Groups: power (J1, U1, C1–C5), PULSE buffer (R1, R2, Q1, J2),
    DIR buffer (R3, R4, Q2, J3), signal terminals (J4–J10, left edge, rot=90°),
    Black Pill headers (J11, J12)
  - Runs from chroot; KiCad must have IPC API enabled

- `stepper_sc/pcb_edge.py` — draws 90×120mm Edge.Cuts board outline via IPC
  - Corners: (25, 25) → (115, 145) mm
  - Uses `seg.proto.shape.segment.{start,end}.{x,y}_nm` proto structure
    (not `seg.proto.{start,end}` — important proto layout detail)

- `stepper_sc/demo_orbit.py` — live IPC demo: orbits first footprint in a circle
  - 15mm radius, 60 steps, 0.05s delay (~3s/orbit)
  - Restores original position on KeyboardInterrupt
  - Confirmed working in KiCad 9.0.6

### Repository
- GitHub: `git@github.com:smooker/cspcb.git`
- `firmware/PyCortexMDebug` added as git submodule
- `firmware/STM32F411.svd` tracked in git
- `.gitignore` covers build artefacts, KiCad temporaries, venv

---

## [2026-03-07] session 1 — schematic generation

### Added
- `fw_to_net.py` — parses `firmware/Core/Inc/main.h` GPIO defines → KiCad Format-E netlist
  - Output: `howto_sch_and_then_api/stepper_sc.net`
  - 24 components, 17 nets
  - PULSE/DIR signals → `output_npn` template (R_base + R_bgnd + Q + J_out)
  - All other signals → `input_direct` (J connector only)

- `howto_sch_and_then_api/stepper_sc_gen.py` — netlist → `stepper_sc.kicad_sch`
  - Grid layout with power symbols and no-connects
  - ERC: clean (0 errors, 0 warnings)

- `howto_sch_and_then_api/stepper_sc.net` — generated netlist (committed)
- `stepper_sc/stepper_sc.kicad_sch` — generated schematic (committed)
- `stepper_sc/stepper_sc.kicad_pro` — KiCad project file

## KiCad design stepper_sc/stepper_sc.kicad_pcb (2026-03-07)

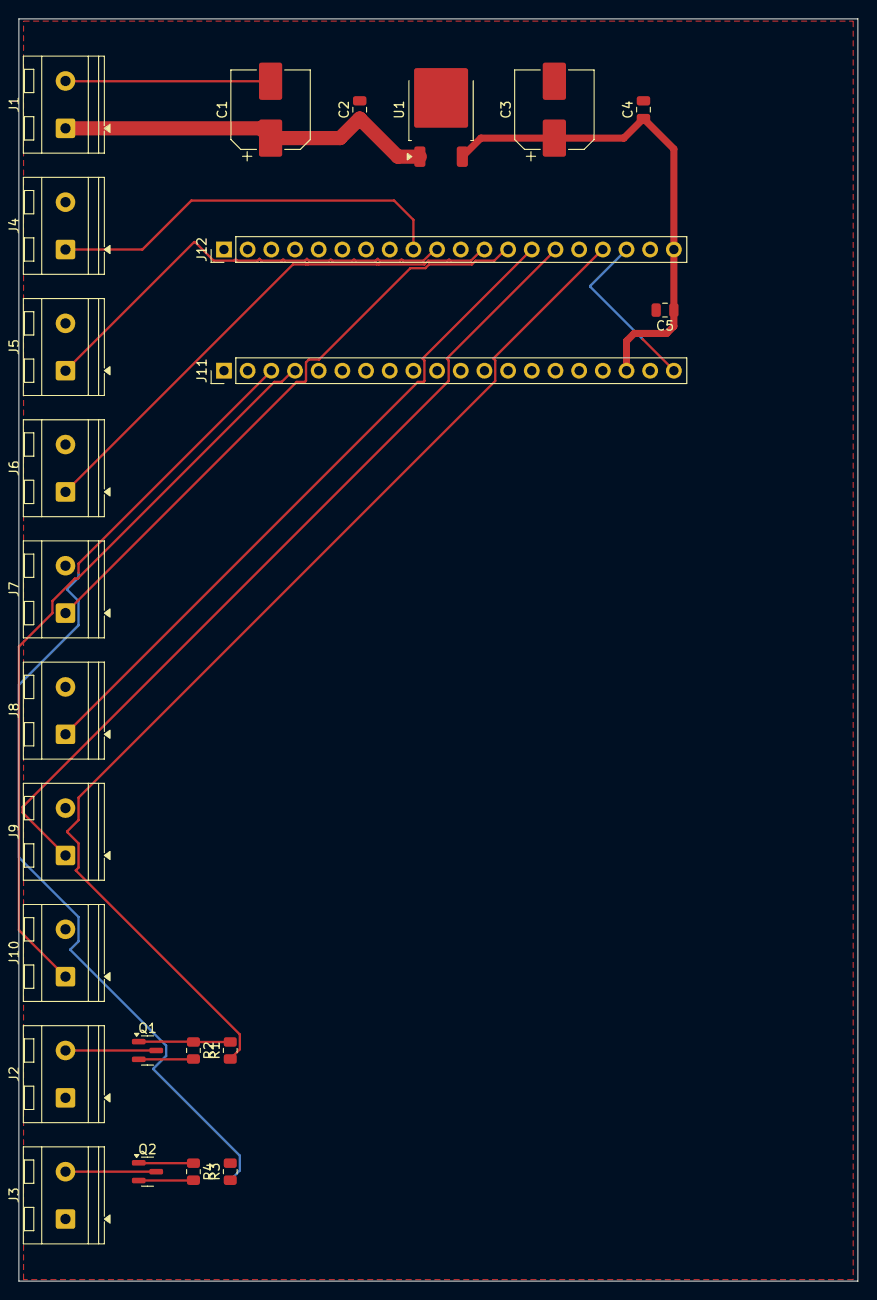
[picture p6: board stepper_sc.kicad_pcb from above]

Board: 2 copper layers, 90.0 x 135.4 mm, 24 parts (0 on the bottom side), 17 nets.

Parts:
C1: 47uF; CP_Elec_8x6.2
C2, C4, C5: 100nF; C_0805_2012Metric
C3: 100uF; CP_Elec_8x6.2
J1: PWR_24V; TerminalBlock_RND_205-00232_1x02_P5.08mm_Horizontal
J2: PUL; TerminalBlock_RND_205-00232_1x02_P5.08mm_Horizontal
J3: DIR; TerminalBlock_RND_205-00232_1x02_P5.08mm_Horizontal
J4: ES_L; TerminalBlock_RND_205-00232_1x02_P5.08mm_Horizontal
J5: ES_R; TerminalBlock_RND_205-00232_1x02_P5.08mm_Horizontal
J6: JOGL; TerminalBlock_RND_205-00232_1x02_P5.08mm_Horizontal
J7: JOGR; TerminalBlock_RND_205-00232_1x02_P5.08mm_Horizontal
J8: STEPL; TerminalBlock_RND_205-00232_1x02_P5.08mm_Horizontal
J9: STEPR; TerminalBlock_RND_205-00232_1x02_P5.08mm_Horizontal
J10: BUZZ; TerminalBlock_RND_205-00232_1x02_P5.08mm_Horizontal
J11: Black_Pill_front; PinHeader_1x20_P2.54mm_Vertical
J12: Black_Pill_back; PinHeader_1x20_P2.54mm_Vertical
Q1, Q2: BC547; SOT-23
R1, R3: 1k; R_0805_2012Metric
R2, R4: 10k; R_0805_2012Metric
U1: 78M05; TO-252-2

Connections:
+3.3V: J11.20, J12.18
+5V: C3.1, C4.1, C5.1, J2.1, J3.1, J11.18, J12.20, U1.3
+24V: C1.1, C2.1, J1.1, U1.1
GND: C1.2, C2.2, C3.2, C4.2, C5.2, J1.2, J4.2, J5.2, J6.2, J7.2, J8.2, J9.2, J10.2, J11.19, J12.19, Q1.2, Q2.2, R2.2, R4.2, U1.2
unnamed: J2.2, Q1.3
unnamed: J3.2, Q2.3
unnamed: J10.1, J11.4
unnamed: J11.3, R3.1
unnamed: J4.1, J12.9
unnamed: J5.1, J12.10
unnamed: J6.1, J12.12
unnamed: J7.1, J12.13
unnamed: J8.1, J12.14
unnamed: J9.1, J12.15
unnamed: J12.17, R1.1
unnamed: Q1.1, R1.2, R2.1
unnamed: Q2.1, R3.2, R4.1

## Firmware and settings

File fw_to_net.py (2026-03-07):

#!/usr/bin/env python3
"""
fw_to_net.py — Generate KiCad netlist (Format-E) from firmware main.h

Pipeline:
  firmware/Core/Inc/main.h  →  fw_to_net.py  →  stepper_sc.net

How it works:
  1. Parse #define SIGNAL_Pin / SIGNAL_GPIO_Port from main.h
  2. Map GPIO port+pin → Black Pill header connector pin (J11A / J11B)
  3. For each signal, apply template:
       output_npn  → R_base(1k) + R_bgnd(10k) + Q(BC547) + J_out(2-pin screw)
       input_direct→ J_in(2-pin screw, pin1=signal, pin2=GND)
       skip        → LED_USER and other on-board-only signals
  4. Add static BOM: power supply (U1, C1-C5, J1) + BP headers (J11A, J11B)
  5. Write .net file
"""

import re, os, datetime

HERE     = os.path.dirname(os.path.abspath(__file__))
MAIN_H   = os.path.join(HERE, 'firmware', 'Core', 'Inc', 'main.h')
OUT_NET  = os.path.join(HERE, 'howto_sch_and_then_api', 'stepper_sc.net')

# ── Black Pill v3.1 — GPIO → (connector, connector_pin) ─────────────────────
# Front row  J11A: BP pins  1-20  (USB end, left→right)
# Back  row  J11B: BP pins 21-40  (non-USB end, right→left), J11B pin N = BP pin 20+N
BP_PIN_MAP = {
    # J11A (front row, BP pins 1-20)
    ('GPIOB', 12): ('J11A',  1),  ('GPIOB', 13): ('J11A',  2),
    ('GPIOB', 14): ('J11A',  3),  ('GPIOB', 15): ('J11A',  4),
    ('GPIOA',  8): ('J11A',  5),  ('GPIOA',  9): ('J11A',  6),
    ('GPIOA', 10): ('J11A',  7),  ('GPIOA', 11): ('J11A',  8),
    ('GPIOA', 12): ('J11A',  9),  ('GPIOA', 15): ('J11A', 10),
    ('GPIOB',  3): ('J11A', 11),  ('GPIOB',  4): ('J11A', 12),
    ('GPIOB',  5): ('J11A', 13),  ('GPIOB',  6): ('J11A', 14),
    ('GPIOB',  7): ('J11A', 15),  ('GPIOB',  8): ('J11A', 16),
    ('GPIOB',  9): ('J11A', 17),
    # pin 18=5V, 19=GND, 20=3V3 — handled in static nets

    # J11B (back row, BP pins 21-40)
    ('GPIOC', 13): ('J11B',  2),  # PC13 = LED_USER
    ('GPIOC', 14): ('J11B',  3),  ('GPIOC', 15): ('J11B',  4),
    ('GPIOA',  0): ('J11B',  6),  ('GPIOA',  1): ('J11B',  7),
    ('GPIOA',  2): ('J11B',  8),  ('GPIOA',  3): ('J11B',  9),
    ('GPIOA',  4): ('J11B', 10),  ('GPIOA',  5): ('J11B', 11),
    ('GPIOA',  6): ('J11B', 12),  ('GPIOA',  7): ('J11B', 13),
    ('GPIOB',  0): ('J11B', 14),  ('GPIOB',  1): ('J11B', 15),
    ('GPIOB',  2): ('J11B', 16),  ('GPIOB', 10): ('J11B', 17),
    # pin 18=3V3, 19=GND, 20=5V — handled in static nets
}

# ── Signal configuration ─────────────────────────────────────────────────────
# type:
#   'output_npn'   → NPN buffer (R_base + R_bgnd + Q + J_out)
#   'input_direct' → direct connector (J_in, pin1=signal, pin2=GND)
#   'skip'         → on-board only, no external connection
#
# connector_label: value field for the output/input screw terminal
# description:     goes into comp description field

SIGNAL_CONFIG = {
    'LED_USER': {
        'type': 'skip',
    },
    'PULSE': {
        'type': 'output_npn',
        'connector_label': 'PUL',
        'description': 'CWD556 PUL: pin1=PUL+(+5V), pin2=PUL-(Q collector). Opto LED inside driver.',
    },
    'DIR': {
        'type': 'output_npn',
        'connector_label': 'DIR',
        'description': 'CWD556 DIR: pin1=DIR+(+5V), pin2=DIR-(Q collector). Opto LED inside driver.',
    },
    'ES_L': {
        'type': 'input_direct',
        'connector_label': 'ES_L',
        'description': 'Endstop left — active LOW both edges',
    },
    'ES_R': {
        'type': 'input_direct',
        'connector_label': 'ES_R',
        'description': 'Endstop right — active LOW both edges',
    },
    'BUTT_JOGL': {
        'type': 'input_direct',
        'connector_label': 'JOGL',
        'description': 'Jog left button — active LOW both edges',
    },
    'BUTT_JOGR': {
        'type': 'input_direct',
        'connector_label': 'JOGR',
        'description': 'Jog right button — active LOW both edges',
    },
    'BUTT_STEPL': {
        'type': 'input_direct',
        'connector_label': 'STEPL',
        'description': 'Step left button — active LOW both edges',
    },
    'BUTT_STEPR': {
        'type': 'input_direct',
        'connector_label': 'STEPR',
        'description': 'Step right button — active LOW both edges',
    },
    'BUZZ': {
        'type': 'input_direct',   # direct connector, driven by BP pin
        'connector_label': 'BUZZ',
        'description': 'Buzzer output',
    },
}

# ── Static BOM ───────────────────────────────────────────────────────────────
FP_SCREW   = 'TerminalBlock_RND:TerminalBlock_RND_205-00232_1x02_P5.08mm_Horizontal'
FP_HEADER  = 'Connector_PinHeader_2.54mm:PinHeader_1x20_P2.54mm_Vertical'
FP_CAP_TH  = 'Capacitor_THT:CP_Radial_D8.0mm_P3.50mm'
FP_CAP_SMD = 'Capacitor_SMD:C_0805_2012Metric'
FP_RES_SMD = 'Resistor_SMD:R_0805_2012Metric'
FP_TO92    = 'Package_TO_SOT_THT:TO-92_Inline'
FP_TO252   = 'Package_TO_SOT_SMD:TO-252-2'

STATIC_COMPS = [
    # ref, value, footprint, description, lib, part, tstamp
    ('U1',   '78M05',         FP_TO252,   '5V linear regulator',
     'Regulator_Linear', 'L78M05_TO252',   'u1-78m05'),
    ('C1',   '47uF',          FP_CAP_TH,  '78M05 input bulk cap',
     'Device',           'C_Polarized',    'c1-47u-in'),
    ('C2',   '100nF',         FP_CAP_SMD, '78M05 input decoupling',
     'Device',           'C',              'c2-100n-in'),
    ('C3',   '100uF',         FP_CAP_TH,  '78M05 output bulk cap',
     'Device',           'C_Polarized',    'c3-100u-out'),
    ('C4',   '100nF',         FP_CAP_SMD, '78M05 output decoupling',
     'Device',           'C',              'c4-100n-out'),
    ('C5',   '100nF',         FP_CAP_SMD, 'Black Pill VIN decoupling',
     'Device',           'C',              'c5-100n-bp'),
    ('J1',   'PWR_24V',       FP_SCREW,   'Power input 24V + GND',
     'Connector',        'Conn_01x02_Screw', 'j1-pwr'),
    ('J11A', 'Black_Pill_front', FP_HEADER,
     'Black Pill front row — pins 1-20, USB end left: B12..B9,5V,GND,3V3',
     'Connector',        'Conn_01x20',     'j11a-bp-front'),
    ('J11B', 'Black_Pill_back', FP_HEADER,
     'Black Pill back row — BP pins 21-40, J11B pin 1=BP21(VBAT)..pin 20=BP40(5V)',
     'Connector',        'Conn_01x20',     'j11b-bp-back'),
]

# ── helpers ──────────────────────────────────────────────────────────────────

def parse_main_h(path):
    """Return {SIGNAL_NAME: (port_str, pin_int)} from main.h #defines."""
    with open(path) as f:
        txt = f.read()

    pins  = {}
    ports = {}

    for m in re.finditer(r'#define\s+(\w+)_Pin\s+GPIO_PIN_(\d+)', txt):
        pins[m.group(1)] = int(m.group(2))

    for m in re.finditer(r'#define\s+(\w+)_GPIO_Port\s+(GPIO[A-Z])', txt):
        ports[m.group(1)] = m.group(2)

    signals = {}
    for sig in pins:
        if sig in ports:
            signals[sig] = (ports[sig], pins[sig])
    return signals


def node(ref, pin, pinfunc='~', pintype='passive'):
    return f'      (node (ref "{ref}")  (pin "{pin}") (pinfunction "{pinfunc}") (pintype "{pintype}"))'


def comp_block(ref, value, fp, desc, lib, part, tstamp):
    lines = [f'    (comp (ref "{ref}")']
    lines.append(f'      (value "{value}")')
    lines.append(f'      (footprint "{fp}")')
    if desc:
        lines.append(f'      (description "{desc}")')
    lines.append(f'      (libsource (lib "{lib}") (part "{part}"))')
    lines.append(f'      (sheetpath (names "/") (tstamps "/"))')
    lines.append(f'      (tstamp "{tstamp}")')
    lines.append(f'    )')
    return '\n'.join(lines)


# ── main ─────────────────────────────────────────────────────────────────────

def main():
    # 1. Parse firmware
    signals = parse_main_h(MAIN_H)
    print(f'Parsed {len(signals)} signals from main.h:')
    for sig, (port, pin) in sorted(signals.items()):
        cfg = SIGNAL_CONFIG.get(sig, {})
        print(f'  {sig:16s}  {port} pin {pin:2d}  → {cfg.get("type","unknown")}')

    # 2. Build component list and nets
    comps  = []   # list of comp_block strings
    nets   = {}   # net_name → [node strings]

    net_code = [0]
    def next_code():
        net_code[0] += 1
        return str(net_code[0])

    def ensure_net(name):
        if name not in nets:
            nets[name] = []
        return name

    # Static power nets
    for n in ('+24V', '+5V', 'GND', '+3.3V'):
        ensure_net(n)

    # Static components
    for s in STATIC_COMPS:
        ref, value, fp, desc, lib, part, tstamp = s
        comps.append(comp_block(ref, value, fp, desc, lib, part, tstamp))

    # Static net nodes — power supply
    nets['+24V'] += [
        node('J1',  '1', 'Pin_1',  'passive'),
        node('U1',  '1', 'VI',     'power_in'),
        node('C1',  '1', '+',      'passive'),
        node('C2',  '1', '~',      'passive'),
    ]
    nets['+5V'] += [
        node('U1',  '3', 'VO',     'power_out'),
        node('C3',  '1', '+',      'passive'),
        node('C4',  '1', '~',      'passive'),
        node('C5',  '1', '~',      'passive'),
        node('J11A','18','Pin_18', 'passive'),
        node('J11B','20','Pin_20', 'passive'),
    ]
    nets['GND'] += [
        node('J1',   '2', 'Pin_2',  'passive'),
        node('U1',   '2', 'GND',    'power_in'),
        node('C1',   '2', '-',      'passive'),
        node('C2',   '2', '~',      'passive'),
        node('C3',   '2', '-',      'passive'),
        node('C4',   '2', '~',      'passive'),
        node('C5',   '2', '~',      'passive'),
        node('J11A','19', 'Pin_19', 'passive'),
        node('J11B','19', 'Pin_19', 'passive'),
    ]
    nets['+3.3V'] += [
        node('J11A','20','Pin_20', 'passive'),
        node('J11B','18','Pin_18', 'passive'),
    ]

    # 3. Process signals — counters for dynamic ref assignment
    q_idx  = 0
    r_idx  = 0
    j_idx  = 1   # J1=power, so start at J2

    # Sort signals: outputs first, then inputs, for clean numbering
    def sort_key(item):
        sig, (port, pin) = item
        cfg = SIGNAL_CONFIG.get(sig, {})
        t = cfg.get('type', 'z')
        order = {'output_npn': 0, 'input_direct': 1, 'skip': 2}.get(t, 3)
        return (order, port, pin)

    for sig, (port, pin) in sorted(signals.items(), key=sort_key):
        cfg = SIGNAL_CONFIG.get(sig, {'type': 'input_direct',
                                      'connector_label': sig,
                                      'description': f'{port}{pin} signal'})
        sig_type = cfg['type']

        if sig_type == 'skip':
            print(f'  SKIP {sig}')
            continue

        # Net name for this MCU signal
        port_letter = port.replace('GPIO', '')   # 'A', 'B', 'C'
        net_sig = f'P{port_letter}{pin}_{sig}'
        ensure_net(net_sig)

        # BP header connection
        bp_key = (port, pin)
        if bp_key in BP_PIN_MAP:
            bp_conn, bp_pin = BP_PIN_MAP[bp_key]
            nets[net_sig].append(
                node(bp_conn, str(bp_pin), f'Pin_{bp_pin}', 'passive')
            )
        else:
            print(f'  WARN: {sig} ({port} pin {pin}) not in BP_PIN_MAP')

        j_idx += 1
        j_ref = f'J{j_idx}'
        label = cfg.get('connector_label', sig)
        desc  = cfg.get('description', '')

        if sig_type == 'output_npn':
            # ── NPN buffer template ──────────────────────────────────────
            q_idx += 1
            r_idx += 1
            q_ref     = f'Q{q_idx}'
            r_base    = f'R{r_idx * 2 - 1}'   # R1, R3, R5...
            r_bgnd    = f'R{r_idx * 2}'        # R2, R4, R6...
            net_base  = f'NET_{sig}_BASE'
            net_col   = f'NET_{sig}_COL'
            ensure_net(net_base)
            ensure_net(net_col)

            comps.append(comp_block(
                r_base, '1k', FP_RES_SMD,
                f'{q_ref} base resistor — {port_letter}{pin} to base',
                'Device', 'R', f'{r_base.lower()}-1k-base-{sig.lower()}'))
            comps.append(comp_block(
                r_bgnd, '10k', FP_RES_SMD,
                f'{q_ref} base pull-down to GND',
                'Device', 'R', f'{r_bgnd.lower()}-10k-bgnd-{sig.lower()}'))
            comps.append(comp_block(
                q_ref, 'BC547', FP_TO92,
                f'NPN buffer {sig}: MCU({port_letter}{pin})->{r_base}->B, E->GND, C->{j_ref}({label}-)',
                'Device', 'Q_NPN', f'{q_ref.lower()}-npn-{sig.lower()}'))
            comps.append(comp_block(
                j_ref, label, FP_SCREW, desc,
                'Connector', 'Conn_01x02_Screw', f'{j_ref.lower()}-{sig.lower()}'))

            # nets
            nets[net_sig]  += [node(r_base, '1', '~', 'passive')]
            nets[net_base] += [
                node(r_base, '2', '~', 'passive'),
                node(r_bgnd, '1', '~', 'passive'),
                node(q_ref,  'B', 'B', 'input'),
            ]
            nets['GND']    += [
                node(r_bgnd, '2', '~', 'passive'),
                node(q_ref,  'E', 'E', 'passive'),
            ]
            nets['+5V']    += [node(j_ref, '1', 'Pin_1', 'passive')]
            nets[net_col]  += [
                node(q_ref,  'C', 'C', 'passive'),
                node(j_ref,  '2', 'Pin_2', 'passive'),
            ]

        elif sig_type == 'input_direct':
            # ── direct connector ─────────────────────────────────────────
            comps.append(comp_block(
                j_ref, label, FP_SCREW, desc,
                'Connector', 'Conn_01x02_Screw', f'{j_ref.lower()}-{sig.lower()}'))

            nets[net_sig] += [node(j_ref, '1', 'Pin_1', 'passive')]
            nets['GND']   += [node(j_ref, '2', 'Pin_2', 'passive')]

        print(f'  {sig:16s}  {q_ref if sig_type=="output_npn" else "     "} {j_ref}  net={net_sig}')

    # 4. Serialise
    lines = []
    lines.append('(export (version "E")')
    lines.append('  (design')
    lines.append(f'    (source "firmware/Core/Inc/main.h")')
    lines.append(f'    (date "{datetime.date.today().isoformat()}")')
    lines.append(f'    (tool "fw_to_net.py — generated from firmware")')
    lines.append('    (sheet (number "1") (name "/") (tstamps "/"))')
    lines.append('  )')
    lines.append('')
    lines.append('  (components')
    for c in comps:
        lines.append(c)
    lines.append('  )')
    lines.append('')
    lines.append('  (libparts)')
    lines.append('  (libraries)')
    lines.append('')
    lines.append('  (nets')
    for code, (name, nodes) in enumerate(nets.items(), start=1):
        lines.append(f'    (net (code "{code}") (name "{name}")')
        for n in nodes:
            lines.append(n)
        lines.append('    )')
    lines.append('  )')
    lines.append(')')

    with open(OUT_NET, 'w') as f:
        f.write('\n'.join(lines) + '\n')

    print(f'\nWritten: {OUT_NET}')
    print(f'  {len(comps)} components, {len(nets)} nets')


if __name__ == '__main__':
    main()

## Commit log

2026-03-07 Initial commit: stepper_sc PCB project
    STM32F411 (Black Pill) stepper controller board with firmware-driven
    netlist pipeline: main.h → fw_to_net.py → stepper_sc.net → stepper_sc_gen.py → KiCad schematic.
    ERC-clean schematic generated. PCB placement next.
    [stepper_sc.kicad_sch]
2026-03-07 Add STM32F411.svd for GDB/PyCortexMDebug debugging
2026-03-07 Add PyCortexMDebug as git submodule
    For GDB peripheral register pretty-printing with STM32F411.svd.
2026-03-07 Add STM32CubeMX project file (stepper_sc.ioc)
2026-03-07 Update firmware/README.md with current project info
    Replace stale bootstrap description with actual signal table,
    build instructions, motion/EEPROM notes, and pipeline reference.
2026-03-07 Add PCB layout scripts + kipy footprint placement fix
    - pcb_place.py: place all 24 footprints via kipy IPC API
    Fixed critical bug: must use fp.position = Vector2.from_xy_mm(x, y)
    and fp.orientation = Angle.from_degrees(rot) — direct proto field
    writes bypass the property setter that moves all children (KiCad 9
    stores pad/silk/courtyard at absolute coords).
    - pcb_edge.py: draw 90×120mm Edge.Cuts outline via IPC
    - demo_orbit.py: orbit single footprint (live IPC demo, KiCad 9.0.6)
    - demo_orbit_all.py: orbit all 24 footprints simultaneously with
    per-footprint phase offset — galaxy ripple effect
    - CHANGELOG.md: session 2 + session 3 milestones documented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
    [stepper_sc.kicad_pcb]
2026-03-07 Add galaxy screenshot — 24 footprints orbiting live in PCBnew
    All 24 PCB components animated simultaneously via kipy IPC API,
    each orbiting its home position with a phase-shifted ripple effect.
    Captured on 4K display, 2026-03-07.
2026-03-07 Fix orbit scripts: remove update_items (was creating duplicates)
    board.update_items(fp) was adding new footprint copies each frame
    instead of updating in place. fp.position/orientation setters modify
    the object directly — no update_items needed. Also add cleanup script
    logic for ref/value text positions.
2026-03-07 Fix Q1/Q2 net assignments + orbit duplicate bug
    - stepper_sc.kicad_pcb: assign correct nets to Q1 and Q2 pads
    BC547 TO-92_Inline pinout: pad1=C, pad2=B, pad3=E
    Q1: C→Net-(J2-Pin_2), B→Net-(Q1-PadB), E→GND
    Q2: C→Net-(J3-Pin_2), B→Net-(Q2-PadB), E→GND
    Root cause: KiCad couldn't map Q_NPN symbolic pins (B,C,E) to
    numeric pads (1,2,3) during Update PCB from Schematic.
    - demo_orbit_all.py: fix duplicate footprint bug
    Use update_items(fp) without begin_commit/push_commit wrapper.
    Having both caused each fp to be sent twice → 1325 duplicates.
    [stepper_sc.kicad_pcb]
2026-03-07 Change C1 and C3 footprints to SMD electrolytic CP_Elec_8x6.2
    Both 100µF caps replaced: Capacitor_THT:CP_Radial_D8.0mm_P3.50mm
    → Capacitor_SMD:CP_Elec_8x6.2
    Schematic edited directly (kicad-sch-api strips lib_symbols on save —
    do not use it for footprint changes on this schematic).
    PCB updated via F8 Update PCB from Schematic.
    [stepper_sc.kicad_sch]
2026-03-07 PCB: swap C1/C3→CP_Elec_8x6.2 SMD, Q1/Q2→SOT-23 SMD; assign pad nets
    - C1, C3: Capacitor_THT:CP_Radial_D8.0mm_P3.50mm → Capacitor_SMD:CP_Elec_8x6.2
    - Q1, Q2: Package_TO_SOT_THT:TO-92_Inline → Package_TO_SOT_SMD:SOT-23
    - Q1 pads: pad1(B)→Net-(Q1-PadB), pad2(E)→GND, pad3(C)→Net-(J2-Pin_2)
    - Q2 pads: pad1(B)→Net-(Q2-PadB), pad2(E)→GND, pad3(C)→Net-(J3-Pin_2)
    - Re-placed all 24 footprints after footprint swap
    [stepper_sc.kicad_pcb, stepper_sc.kicad_sch]
2026-03-07 PCB: reorganize terminal block column, extend board outline
    - Move J1 above J4 in the left screw terminal column (rot=90°, 13mm spacing)
    - Move J2, J3 into the same column below J10 (y=141, y=154, rot=90°)
    - Extend edge cuts to fit full terminal column (J1→J2→J3→J4→...→J10)
    - Board outline: x=25→115, y=25.26→160.66 (4.00mm gap above J1 and below J3 body)
    [stepper_sc.kicad_pcb]
2026-03-07 PCB: layout power rail row — caps, regulator, equal spacing
    - J1 placed in terminal column above J4, rot=90°, 13mm spacing
    - J2, J3 moved into terminal column below J10 (y=141, y=154)
    - Edge cuts extended and fine-tuned: 4.00mm gap above J1 and below J3 bodies
    - C1 rotated +90° to match J1 polarity (+24V at bottom, GND at top)
    - C2, C3, C4 rotated +90° to match polarity consistently
    - C4 moved from (82,48) to power rail row at y=35
    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
    [stepper_sc.kicad_pcb]
2026-03-07 PCB: place NPN buffer groups Q1/Q2 aligned to screw terminals
    - Q1 group (Q1 rot=0°, R2 rot=-90°, R1 rot=90°) at y=135.92
    Q1 pad3 (collector) aligned with J2 pad2 — direct horizontal trace
    - Q2 group (Q2 rot=0°, R4 rot=-90°, R3 rot=90°) at y=148.92
    Q2 pad3 (collector) aligned with J3 pad2 — direct horizontal trace
    - Both groups 2mm right of terminal block edge, equal body spacing
    [stepper_sc.kicad_pcb]
2026-03-07 PCB: align C5 +5V pad with J12 pin20, shift J11/J12/C5 group +10mm right
    - C5 pad1 (+5V) x-aligned with J12 pin20 (+5V) at x=95.26mm
    - J11/J12/C5 group shifted +10mm right (J11/J12 pin1 now at x=47)
    - Add align_c5_j12.py helper script
    [stepper_sc.kicad_pcb]
2026-03-07 PCB: add GND copper pour on F.Cu and B.Cu via IPC
    - gnd_pour.py: creates filled Zone on both layers, net=GND
    - Zone outline 0.5mm inset from Edge.Cuts (25.5,25.5)..(114.5,160.5)
    - Zones refilled automatically after creation
    [stepper_sc.kicad_pcb]
2026-03-07 media: add 3D viewer export stepper_sc_3d_2026-03-07.png
2026-03-07 router: first homegrown A* PCB autorouter
    - router/grid.py: two-layer obstacle grid (F.Cu + B.Cu), 0.1mm resolution
    - router/astar.py: A* pathfinder, 8-directional + via transitions
    - router/segments.py: convert A* path to 45° track segments
    - router/router.py: main entry point, queries KiCad IPC, routes all unconnected nets
    First run: 9 nets routed, 124 tracks + 4 vias, 0 failures.
    No crossings — per-net pad exclusion prevents short circuits.
    [stepper_sc.kicad_pcb]
2026-03-12 Add -Wno-error=unused-parameter for HAL + post_cubemx.sh
    STM32 HAL has unused 'Banks' parameter in flash_ex.c — allow it
    as warning instead of error. post_cubemx.sh re-applies the patch
    after CubeMX regenerates Makefile.
2026-03-12 Clean up script2.gdb — remove commented-out lines
2026-03-12 Remove elf argument from go_gdb.sh — script2.gdb handles it
2026-03-12 Add SVD register viewer (PyCortexMDebug + STM32F411.svd)
2026-03-12 Fix TARGET name: stepper → stepper_sc
2026-03-12 Add FIRMWARE.md — complete firmware documentation
2026-03-13 Fix decel ramp bug + add udev rules and test script
    decelIndex was set to 0 (slow end) on CONST→DECEL transition,
    causing instant speed drop from full to minimum. Fixed to start
    from decelSize-1 (fast end) for proper deceleration ramp.
    Added 99-steppersys.rules: unified udev rules for Black Pill CDC,
    Black Magic Probe (GDB+UART), and FX2 Saleae logic analyzer.
    Added udevtest.sh to verify rules against ttyACM devices.
2026-03-13 Add FX2 connection test procedure to FIRMWARE.md
    GDB-based GPIO toggle test for verifying PB10→D7 (PULSE) and
    PB14→D6 (DIR) wiring between Black Pill and FX2 Saleae Logic.
    Includes register reference, step-by-step, and one-liner commands.
2026-03-13 Add capture_both.sr — data acquisition milestone for Claude
    First successful autonomous capture from chroot: sigrok-cli + FX2 Saleae
    driven by Claude, motor commands via CDC. Two moves (mover 5 + movel 5)
    showing symmetric accel/decel ramps and DIR flip. 100kHz, 6s, D6+D7.
2026-03-13 Add pulse.sh and pulseview session with stepper decoders
    pulse.sh generates .pvs setup file and opens pulseview with
    edge counter (resets on DIR change) + stepper_motor decoder
    (position/speed in mm, 400 steps/mm). Configurable steps_per_mm.
2026-03-13 Add speed analog channel, go.sh workflow, and pulseview screenshot
    - capture_both_speed.sr: computed speed (mm/s) as analog channel
    - capture_both_speed.pvs: pulseview session with decoders + 64px traces
    - go.sh: build/flash/capture/speed/view workflow script
    - capture_all.sr: original pre-fix capture (decel bug evidence)
    - doc/pulseview_capture.png: pulseview screenshot showing ramp
    - FIRMWARE.md: updated capture docs with fix results and viewing instructions
    Key learning: analog channel files in .sr are named analog-1-{N} where
    N = num_logic_channels + analog_index + 1 (e.g. analog-1-9 for 8 logic + 1st analog).
2026-03-13 Fix go.sh: samplerate parsing, analog metadata, speed dropout
    - Parse "100 kHz" / "1 MHz" samplerate strings from metadata
    - Handle total analog=0 (replace, not skip)
    - Drop speed to zero within 2x last pulse period instead of 100ms
2026-03-13 Add triangle + combo captures, auto-generate .pvs in go.sh
    Triangle ramp captures (move 1 — accel never reaches full speed) and
    combo captures (2 triangles + 2 trapezoids in one file). go.sh speed
    command now generates .pvs session file with correct pulseview format:
    trace heights in [view0], URL-encoded analog section, decoder
    annotation classes, and proper GVariant encoding. Updated screenshot
    showing all four ramp profiles.
2026-03-13 Move doc/ to docs/media/, add capture analysis in Bulgarian
    Restructure documentation: doc/ → docs/ with media/ subfolder for
    images. Add capture_analysis.md — verification of timer calculations
    against captured signals (Bulgarian). Fix image links in FIRMWARE.md.
2026-03-13 Add EXTI button/endstop handlers, diag mode, boot banner, prompt
    - 4 buttons (JOGL, JOGR, STEPL, STEPR) with 30ms debounce
    - 2 endstops (ES_L, ES_R) without debounce, instant Stepper_Stop()
    - GPIO changed to PULLUP + FALLING (buttons to GND)
    - EXTI IRQ handlers in stm32f4xx_it.c
    - 'diag' command: toggle diagnostic mode (print-only, no motor action)
    - Boot banner with git hash and build date via Makefile defines
    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
2026-03-13 Fix printf-from-ISR bug, add endstop debounce in diag, test log
    ISR now only sets event flags — all printf moved to ProcessEvents()
    in main loop. Endstops debounced in diag mode only (normal mode
    keeps instant Stepper_Stop for safety). Added input_test_log.md
    documenting the full GDB register test and diag mode validation.
    [main.c]
2026-03-13 Add heartbeat LED, jog hold-to-continuous, RunContinuous, rewrite Stop
    - PC13 LED toggles every 500ms as heartbeat indicator
    - Jog buttons: short press = jogstep, hold >300ms = continuous movement
    - Stepper_RunContinuous(): accel to mmpsmax then run until Stop()
    - Stepper_Stop(): find matching decel index for smooth deceleration
    - Jog EXTI changed to RISING_FALLING for press/release detection
    - Jog state machine: IDLE → PRESSED → CONT → IDLE
    [main.c, stepper.h]
2026-03-13 Add intercommunication docs and GDB command injection script
    - Document User ↔ Target ↔ Claude topology and access methods
    - inject_cmd.sh: inject CDC commands into RX ring buffer via GDB
    - Heartbeat LED documentation (PC13, 500ms toggle)
    - Capture + inject workflow description
2026-03-13 Add combo test command, asymmetric decel capture, updated docs
    - combo command: 4 sequential moves (2 triangles + 2 trapezoids)
    with busy-wait between each — single inject captures all profiles
    - Asymmetric decel: dvdtacc=50, dvdtdecc=100 (decel 2x steeper)
    - Combo capture: 4800 pulses, 4 bursts, all verified on sigrok
    - Pulseview screenshot with speed trace showing asymmetric ramps
    - Updated FIRMWARE.md with combo docs and capture table
2026-03-13 Add buzzer beep, morse boot sequence, diag commands, user manual
    - Morse VGZ boot sequence: V(blocking) → banner → params → G(blocking) → prompt → Z(non-blocking)
    - Non-blocking morse state machine (MorseStart/MorseUpdate in main loop)
    - 50ms buzzer beep on any EXTI event (button/endstop press)
    - diag_inputs (di): toggle input diagnostics mode
    - diag_outputs (do): PULSE+DIR test loop, password protected ("motorola")
    - reset command: clear screen + 50ms flush delay before NVIC_SystemReset
    - Params dump moved after banner (was printing before due to CDC buffering)
    - USER_MANUAL.md: full user-facing documentation
    [main.c]
2026-03-13 Add boot self-test, input enable/disable, fix CSI escape parser
    - Buttons start disabled, enabled after boot self-test passes (morse OK)
    - Boot input check: if any button/endstop stuck LOW, loops CQ CQ CQ DE
    LZ1CCM until fault cleared
    - CDC commands: buttons on/off, endstops on/off
    - Fix ESC sequence parser: swallow full CSI sequences (parameter bytes
    0x20-0x3F + unknown finals) instead of leaking as printable chars
    - Flush RX buffer before main loop to discard minicom init strings
    - Clear screen before boot banner
    - FUN.md: memorable debugging moments from the session
    [main.c]
2026-03-13 Add DIR inversion EEPROM param, multi-cmd inject, pre-homing with EMI
    - dirinv parameter (EEPROM addr 8): inverts DIR pin polarity
    Confirmed: dirinv=1, mover=CW, movel=CCW with optocoupled driver
    - inject_cmd.sh: accepts multiple commands in single GDB session
    ./inject_cmd.sh "cmd1" "cmd2" "cmd3" — one attach/detach for all
    - Fix CSI parser: buttons/endstops commands use lineBuf not cmd
    (sscanf "%s" strips multi-word commands like "buttons off")
    - Align boot banner and params to 47-char separators
    [main.c, stepper.h]
2026-03-13 Add homing procedure, absolute position, morse fix, documentation
    - Home command: debounced GPIO polling (EMI-resistant), configurable
    homespd and homeoff EEPROM params, backoff at 1/10 approach speed
    - Absolute position tracking in prompt (0000.00 > after home)
    - Morse multi-letter fix (MRS_LETTERGAP state)
    - INSTALLER_MANUAL.md: setup guide, EEPROM map, wiring, EMI notes
    - USER_MANUAL.md: full rewrite with all commands documented
    - FUN.md: solar inverter EMI story
    [main.c, stepper.h]
2026-03-13 Add endstop direction blocking, jog release fix, debug EEPROM param
    - esBlocked flag: ES_L hit blocks CCW jog, ES_R blocks CW jog
    - Jog release: no debounce + Stepper_Stop() in ISR for instant stop
    - ES_L excluded from boot self-test (motor may be parked on home switch)
    - Home on ES_L: skip approach, direct backoff + park
    - buttonsEn restored after home procedure
    - debug EEPROM param (addr 11, bit0: verbose button messages)
    - Auto prompt with position when motor stops (wasBusy detection)
    Known: step buttons don't check esBlocked yet (TODO)
    [main.c, stepper.h]
2026-03-13 Add firmware audit report — code review of v0.4-buttons
    Covers bugs (evtFlags race, ISR critical sections, Error_Handler deadlock),
    safety concerns (no soft limits, hardcoded homing distance), and good practices.
2026-03-18 Update documentation: asymmetric ramp analysis, new features
    - capture_analysis.md: full asymmetric ramp analysis from 1MHz captures,
    accel/decel ratio 2.02x confirmed, ASCII velocity profile diagram
    - USER_MANUAL: ES_L boot exclusion, debug param, endstop direction
    blocking, position tracking, jog ISR release, 11 EEPROM params
    - INSTALLER_MANUAL: fix section numbering, debug in EEPROM map,
    homeoff in steps, new software mitigations
    - FIRMWARE.md: dirinv/homespd/homeoff/debug params, home/morse/buttons/
    endstops/di/do commands, asymmetric ramps note, position tracking
2026-03-18 Replace pulseview_combo4.png with asymmetric ramp capture screenshot
    PulseView showing capture_combo_final_speed.sr: 4 combo moves with
    asymmetric ramps (dvdtacc=50, dvdtdecc=100), speed trace, edge counter,
    and stepper motor position/speed decoders.
